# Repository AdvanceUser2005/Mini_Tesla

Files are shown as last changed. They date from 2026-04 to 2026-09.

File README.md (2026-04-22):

# Mini Tesla — Autonomous Mecanum Robot Platform

## Members
Daksh Gupta, Computer Engineering Student (2028)
mailtodaksh@vt.edu

## Mentor
MENTOR NAME HERE

## Current Status
IN PROGRESS

## Project Overview

The Mini Tesla is an autonomous omnidirectional robotic platform built on a four-wheel mecanum drivetrain, capable of moving in any direction — forward, lateral, diagonal, and rotational — without needing to reorient itself. The platform is designed as a full-stack research and engineering vehicle that bridges mechanical design, embedded systems, and autonomous robotics software.

At the mechanical core, the robot features a custom-built two-ratio gearbox designed and fabricated in-house, enabling adaptive gear shifting between high-speed flat terrain mode and high-torque incline traversal mode. The drivetrain uses four Pololu 37D bare DC motors (24V, 64 CPR encoder, no internal gearbox) feeding directly into the custom transmission — maximizing regenerative braking efficiency by eliminating the energy loss of a factory gearbox. Custom spring-damper shock absorbers are designed and tuned for outdoor terrain traversal, and a hydraulic braking circuit — engineered from first principles including master/slave cylinder sizing and fluid bleeding — provides active braking and hill-hold capability.

The autonomy stack runs on an NVIDIA Jetson Orin Nano Super (67 TOPS) executing ROS 2, with a Teensy 4.1 microcontroller handling real-time motor control, PID velocity loops, encoder feedback, and actuator commands over CAN/serial. Perception is handled by an Intel RealSense D435 RGB-D camera and an RPLIDAR A1 2D LiDAR, enabling SLAM-based mapping, Nav2 autonomous navigation, and an Automatic Emergency Braking (AEB) system via depth threshold detection. An AI pipeline running YOLO on the Jetson GPU enables object detection and person-following behavior. The robot also supports WiFi and Bluetooth remote control for manual override alongside full autonomous operation.

A digital twin of the platform is built in NVIDIA Isaac Sim, enabling hardware-in-the-loop (HIL) simulation and algorithm validation before deployment to the physical robot. The project spans three semesters — Spring, Summer, and Fall 2026 — with three defined milestones culminating in a full autonomous demonstration.

## Educational Value Added

This project develops hands-on expertise across six engineering disciplines simultaneously, making it one of the most comprehensive student robotics projects in scope:

**Mechanical Design & Manufacturing** — Students learn to design a multi-ratio planetary gearbox from scratch, understanding gear ratio theory, torque multiplication, and how automotive transmissions work at a fundamental level. Custom shock absorbers are designed using spring-damper physics, spring rate selection (k = F/x), and damping coefficient tuning. A hydraulic brake circuit is engineered from Pascal's Law up — including master/slave cylinder bore sizing, brake fluid selection, and system bleeding technique. FEA (Finite Element Analysis) is used to validate structural components before fabrication.

**Embedded Systems & Real-Time Control** — The Teensy 4.1 runs deterministic real-time firmware handling four simultaneous quadrature encoder interrupts, four independent PID velocity loops, PWM motor command output, servo control for the gear selector, and solenoid actuation for the hydraulic brake — all at 1 kHz without timing conflicts. Students learn CAN bus communication, hardware timer configuration, and interrupt-driven architecture.

**Robotics Software (ROS 2)** — The full ROS 2 stack is implemented from scratch: mecanum inverse kinematics node, wheel odometry, IMU-fused localization, SLAM mapping with RPLIDAR, and Nav2 goal-directed navigation with dynamic obstacle avoidance. Students learn node architecture, topic/service communication, and real-time sensor fusion.

**AI & Computer Vision** — YOLO object detection and person re-identification pipelines run on the Jetson GPU for human-following behavior. The AEB system uses raw RealSense depth data — not AI — for sub-25ms obstacle detection latency, teaching students the difference between classification tasks and safety-critical sensor pipelines.

**Simulation & Digital Twin** — NVIDIA Isaac Sim is used to build a full digital twin of the robot including geometry, sensors, and drivetrain physics. Students learn hardware-in-the-loop testing workflows and sim-to-real transfer techniques used in industry robotics development.

**Communications & Controls** — WiFi and Bluetooth modules provide remote control capability alongside the autonomous stack. Students implement mode-switching logic, teleop integration in ROS 2, emergency stop handling, and failsafe behavior.

## Tasks

### Spring 2026 (Now → May 13)
- [ ] Finalize BOM and place all component orders (motors, MCU, sensors, battery, structural hardware)
- [ ] CAD — Full chassis design in SolidWorks/Fusion 360
- [ ] CAD — Custom 2-ratio gearbox (planetary stages, selector collar, housing)
- [ ] CAD — Shock absorber assemblies (spring-damper bodies, mount points)
- [ ] CAD — Hydraulic brake system (caliper, rotor, master cylinder, lines)
- [ ] FEA — Structural analysis on chassis and gearbox housing
- [ ] Receive and inventory all ordered components
- [ ] Begin manufacturing drawings for CNC/3D print parts

### Summer 2026 (May 26 → July 6)
- [ ] 3D print and CNC machine all custom parts (gearbox bodies, shock housings, brake calipers)
- [ ] Full mechanical assembly — chassis, wheels, gearboxes, shock absorbers
- [ ] Wire all electronics — Teensy, motor drivers, IMU, LiDAR, RealSense, AI PC, WiFi/BT module
- [ ] Flash Teensy firmware — encoder interrupts, PID loops, CAN comms
- [ ] Validate mecanum kinematics — test all four motion vectors
- [ ] Test power regeneration — verify BTS7960 back-EMF current return
- [ ] Test gearbox shifting — servo-actuated selector under load
- [ ] Test hydraulic brakes — caliper engagement, hill-hold force
- [ ] Test remote control — WiFi/BT manual override
- [ ] Isaac Sim — build digital twin, run full-scale simulation tests
- [ ] **MILESTONE #2 target: June 13** — Assembly complete, all wiring done, basic subsystem testing done

### Fall 2026 (Aug 24 → Dec 16)
- [ ] Camera integration — RealSense depth layer into Nav2 costmap
- [ ] AEB system — depth threshold node with real-time priority, direct Teensy serial path
- [ ] YOLO object detection pipeline on Jetson GPU
- [ ] Person-following behavior node
- [ ] Full Nav2 autonomous navigation on real hardware
- [ ] SLAM map generation and localization validation
- [ ] Full system integration testing — all subsystems running simultaneously
- [ ] Documentation — architecture writeup, wiring diagrams, software README
- [ ] **MILESTONE #3 target: Dec 16** — Full autonomous run demonstration

## Design Decisions

**Motor Selection — Pololu 37D Bare Motor (24V, no internal gearbox)**
Chosen over motors with factory gearboxes specifically because the custom gearbox IS the project. Using a bare motor means the only reduction stage is our custom 2-ratio transmission, which maximizes back-drive efficiency for regenerative braking (no factory gearbox eating energy in reverse) and gives us full control over gear ratios. The 64 CPR encoder provides tight velocity feedback for PID.

**Motor Driver — Cytron MDD10A × 2**
Chosen over BTS7960 because it is purpose-built for the 10-12A peak current range of our motors, includes proper overcurrent/overheat protection, has cleaner PWM response, and covers two motors per board — reducing wiring complexity from four boards to two. Supports regenerative braking current routing.

**Microcontroller — Teensy 4.1**
600 MHz ARM Cortex-M7 provides sufficient headroom to run four encoder interrupts, four PID loops, CAN comms to Jetson, servo PWM for gear selector, and hydraulic brake solenoid control simultaneously without timing conflicts. Native CAN bus and solid micro-ROS support for ROS 2 integration via serial.

**Perception — RealSense D435 + RPLIDAR A1 (no OAK-D)**
LiDAR handles 2D SLAM with superior reliability on blank walls and in low light. RealSense adds 3D depth for AEB and close-range obstacle detection. The OAK-D was evaluated and dropped — once LiDAR is in the stack, OAK-D has no unique role. The combo of RealSense + LiDAR outperforms OAK-D + LiDAR in both indoor reliability and outdoor sunlight conditions.

**AEB Design — Depth Threshold, Not Image Recognition**
AEB latency requirement is sub-25ms. Neural network inference adds 50-120ms before a brake signal is even sent. The AEB node reads raw RealSense depth frames, checks the minimum depth value in a forward-facing region of interest, and fires directly to the Teensy over a dedicated high-priority serial path — bypassing the ROS nav stack entirely. Total pipeline latency: ~15-20ms.

**Gearbox — Per-Wheel (not shared axle)**
Each mecanum wheel must spin at an independently controlled speed. Any mechanical coupling between two wheels (e.g. shared differential) destroys omnidirectional capability. All four gearboxes shift simultaneously via a single servo command from Teensy, maintaining synchronized gear state across all wheels.

**No AK60-6 Actuators**
CubeMars AK60-6 was evaluated — excellent motors with integrated FOC and CAN — but at ~$220/unit ($880 for 4 wheels) they consume over half the total budget before any other component is purchased. The Pololu 37D + custom gearbox achieves the educational objectives of the project at a fraction of the cost.

## Design Misc

- **Gearbox Ratios**: High gear 1:1 (flat terrain, max speed), Low gear 2:1 (inclines, max torque). With Pololu 37D at 24V, low gear provides approximately 2× the climbing force.
- **Shock Absorber Tuning**: Spring rate selected based on estimated robot mass ~10-12 kg. Rebound damping oil viscosity to be tuned empirically during summer assembly phase.
- **Hydraulic Brake Hold Force**: Sized to hold robot stationary on 20° incline at full load. Master cylinder bore sized for solenoid actuation force available from Teensy-controlled valve.
- **Regenerative Braking Efficiency**: With bare motor (no internal gearbox) and 1:1 or 2:1 custom transmission, estimated 45-55% energy recovery vs ~12% with a factory 50:1 gearbox.
- **Stereo LiDAR**: If additional 3D mapping capability is needed beyond RealSense, stereo depth from RealSense is fed into RTAB-Map as a second mapping layer. No OAK-D needed.
- **WiFi/BT Remote Control**: Implemented as a ROS 2 teleop node. Autonomous mode and teleop mode are mutually exclusive with a hardware-level mode switch. Emergency stop works in both modes.

## Steps for Documenting Your Design Process

1. **CAD Files** — All SolidWorks/Fusion 360 files version-controlled in project GitHub repo under `/cad`. Export STLs and STEP files for each manufactured part alongside manufacturing drawings (PDF).
2. **FEA Reports** — Document load cases, boundary conditions, mesh parameters, and safety factors for each analyzed component. Export simulation screenshots and summary tables to `/docs/fea`.
3. **Wiring Diagrams** — Full schematic in KiCad or Fritzing showing every electrical connection: Teensy pinout, motor driver wiring, sensor connections, power distribution. Stored in `/docs/electrical`.
4. **Firmware** — Teensy firmware in `/firmware` with inline comments explaining each PID parameter, CAN message format, and interrupt configuration. Include a README with flash instructions.
5. **ROS 2 Packages** — Each subsystem (kinematics, navigation, perception, AEB) is its own ROS 2 package in `/ros2_ws/src`. Include launch files and parameter YAML files.
6. **Test Logs** — After each milestone, document test results: motor RPM vs command, PID step response plots, LiDAR scan accuracy, navigation success rate. Stored in `/docs/test_logs`.
7. **Weekly Log** — Update the Log section of this document every week with what was completed, what blocked progress, and what is planned next.

## BOM + Component Cost

| Component | Category | Qty | Unit Cost | Total |
|---|---|---|---|---|
| NVIDIA Jetson Orin Nano Super (8GB) | Compute | 1 | $249 | $249 |
| Teensy 4.1 Microcontroller | Embedded Control | 1 | $30 | $30 |
| Pololu 37D Bare DC Motor (24V, 64 CPR Encoder) | Drivetrain | 4 | $37.50 | $150 |
| Custom CNC Gearbox — Aluminum, 2-ratio (materials est.) | Transmission | 4 | ~$40 | ~$160 |
| Servo Motor (Gear Selector Actuator) | Transmission | 1 | $30 | $30 |
| Cytron MDD10A Dual Motor Driver | Power Electronics | 2 | $30 | $60 |
| Intel RealSense D435 RGB-D Camera | Perception | 1 | $399 | $399 |
| RPLIDAR A1 (2D LiDAR) | Perception | 1 | $100 | $100 |
| IMU — BNO055 | Sensing | 1 | $25 | $25 |
| WiFi / Bluetooth Module | Communications | 1 | $25 | $25 |
| LiPo Battery Pack (22.2V, 10Ah) | Power | 1 | $150 | $150 |
| Power Management / BMS Board | Power | 1 | $80 | $80 |
| Robot Chassis (Aluminum Frame, Final Stage) | Structure | 1 | $180 | $180 |
| Wiring, Connectors, Fasteners, Misc. Hardware | Misc. | — | — | $120 |
| **TOTAL** | | | | **~$1,758** |

> Custom gearbox cost is a materials estimate only. Machining is done in-house using university shop access. ROS 2, NVIDIA Isaac Sim, and all software tools are free / open-source.

## Timeline

### Spring 2026 — Now → May 13
**Goal**: All CAD complete, all parts ordered and received, FEA validated

| Week | Focus |
|---|---|
| Now – Week 2 | Finalize BOM, place all component orders |
| Week 2 – 4 | CAD — Chassis, gearbox, shock absorbers, hydraulic brakes |
| Week 4 – 5 | FEA analysis on chassis and gearbox housing |
| Week 5 – 6 | Manufacturing drawings, send files to shop / begin 3D printing |
| **May 13** | **🏁 MILESTONE #1 — Chassis (physical), Wheels (mounted), Gearbox (CAD), Brakes (CAD), Shockers (CAD)** |

---

### Summer 2026 — May 26 → July 6
**Goal**: Fully assembled and wired robot with all subsystems individually tested

| Week | Focus |
|---|---|
| Week 1 | 3D print and CNC all custom parts |
| Week 2 | Full mechanical assembly — chassis, gearboxes, shock absorbers, wheels |
| Week 3 | All electronics wiring — Teensy, motor drivers, LiDAR, RealSense, IMU, WiFi/BT, AI PC |
| Week 4 | Teensy firmware — encoders, PID, CAN/serial, gear selector, brake solenoid |
| Week 5 | Testing — mecanum kinematics, regen braking, gearbox shifting, hydraulic brakes |
| Week 6 | Remote control integration + Isaac Sim full-scale simulation |
| **June 13** | **🏁 MILESTONE #2 — Full assembly complete, all wiring done, gearbox + brakes + remote tested** |

> *Break period: July 6 – August 24*

---

### Fall 2026 — Aug 24 → Dec 16
**Goal**: Full autonomous robot with AI perception, SLAM navigation, and AEB — demonstrated live

| Week | Focus |
|---|---|
| Week 1 – 2 | Camera integration — RealSense depth into Nav2 costmap + SLAM |
| Week 3 – 4 | AEB system — depth threshold node, dedicated serial path to Teensy |
| Week 5 – 6 | AI pipeline — YOLO object detection + person following on Jetson |
| Week 7 – 8 | Full ROS 2 stack on hardware — Nav2, localization, sensor fusion |
| Week 9 – 10 | System integration — all subsystems running simultaneously |
| Week 11 – 12 | Testing, debugging, performance tuning |
| Week 13 – 14 | Documentation — architecture writeup, wiring diagrams, software README |
| **Dec 16** | **🏁 MILESTONE #3 — Full autonomous demo: SLAM map, navigate to goal, detect person, AEB trigger** |

## Useful Links

- [Pololu 37D Metal Gearmotor (Bare, 24V, Encoder)](https://www.pololu.com/category/116/37d-mm-metal-gearmotors)
- [Cytron MDD10A Dual Motor Driver](https://www.cytron.io/p-10amp-5v-30v-dc-motor-driver-2-channels)
- [Teensy 4.1 — PJRC](https://www.pjrc.com/store/teensy41.html)
- [NVIDIA Jetson Orin Nano Super Developer Kit](https://developer.nvidia.com/embedded/jetson-orin-nano-developer-kit)
- [Intel RealSense D435](https://www.intelrealsense.com/depth-camera-d435/)
- [RPLIDAR A1](https://www.slamtec.com/en/Lidar/A1)
- [ROS 2 Humble Documentation](https://docs.ros.org/en/humble/)
- [Nav2 Documentation](https://docs.nav2.org/)
- [NVIDIA Isaac Sim](https://developer.nvidia.com/isaac-sim)
- [micro-ROS for Teensy](https://micro.ros.org/)
- [SimpleFOC Library](https://simplefoc.com/)
- [RTAB-Map ROS 2](https://github.com/introlab/rtabmap_ros)

## Log

### Week of April 21, 2026
- Project proposal drafted and submitted
- Component decisions finalized: Pololu 37D bare motor, Cytron MDD10A, Teensy 4.1, RealSense D435 + RPLIDAR A1
- Decided against OAK-D Lite (redundant with RealSense + LiDAR combo)
- Decided against AK60-6 actuators (over budget at $880 for 4 wheels)
- AEB architecture decided: depth threshold on raw RealSense frames, dedicated high-priority serial path to Teensy — no image recognition in the braking loop
- Three-semester timeline established with three milestones (May 13, June 13, Dec 16)
- PowerPoint proposal finalized and submitted
- **Next steps**: Begin chassis CAD, finalize BOM pricing, place first component orders

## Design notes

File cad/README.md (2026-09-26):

# CAD

All mechanical CAD for Mini Tesla. Right now that means the **10C4I** indoor mecanum prototype. 15C4I (the outdoor gear-changing car) has no CAD in this repo yet.

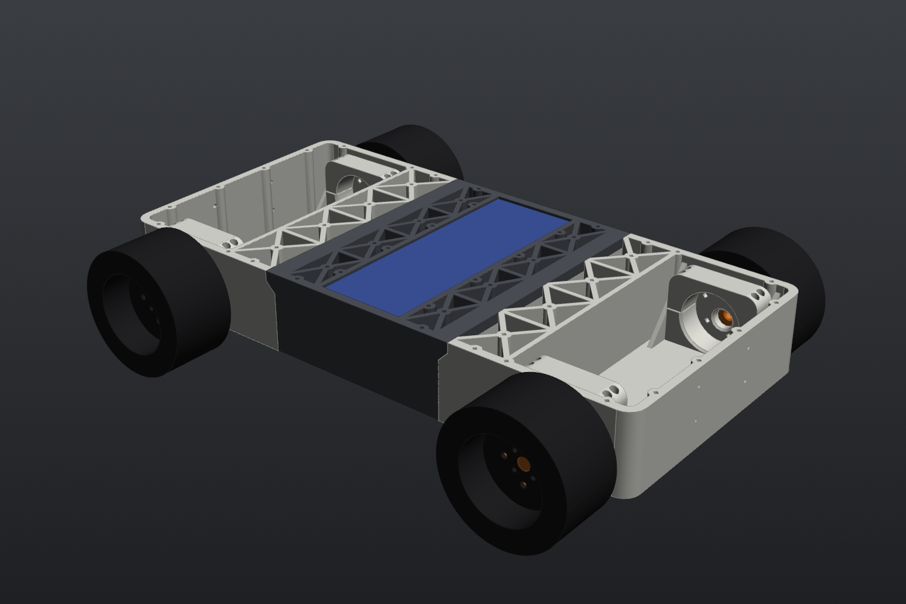
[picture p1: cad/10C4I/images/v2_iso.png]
10C4I v2 assembled


## What's here

| Item | Status | Doc | Files |
|---|---|---|---|
| 10C4I chassis v2 (overview, assembly, hardware) | Designed, **not printed yet**: waiting on coupon results | [10C4I/README.md](10C4I/README.md) | `10C4I/step/10C4I_v2_assembly.step` |
| Center section ×1 | Designed | [parts/center_section.md](10C4I/parts/center_section.md) | `10C4I_v2_center_section_x1.{step,stl}` |
| End section ×2 (front = rear) | Designed | [parts/end_section.md](10C4I/parts/end_section.md) | `10C4I_v2_end_section_x2.{step,stl}` |
| Motor cap ×4 | Designed | [parts/motor_cap.md](10C4I/parts/motor_cap.md) | `10C4I_v2_motor_cap_x4.{step,stl}` |
| Wheel adapter ×4 | Designed | [parts/wheel_adapter.md](10C4I/parts/wheel_adapter.md) | `10C4I_v2_wheel_adapter_x4.{step,stl}` |
| Tolerance coupon | Ready to print, **print this first** | [parts/tolerance_coupon.md](10C4I/parts/tolerance_coupon.md) | `10C4I_tolerance_coupon.{step,stl}` |
| Top mount-point map (56 M2.5 inserts) | Done | [mount_points/](10C4I/mount_points/) | `.csv` + `.png` |
| Bare-motor 2-stage gearbox ×2 | **Not modeled yet**: needs pinion measurements | [parts/bare_motor_gearbox.md](10C4I/parts/bare_motor_gearbox.md) | none |
| Chassis v1 | Superseded by v2, files not kept | [parts/v1_chassis.md](10C4I/parts/v1_chassis.md) | none |

## Layout

```
cad/10C4I/
├── README.md        overall chassis: dimensions, hardware, print + assembly
├── src/             CadQuery source (the real source of truth)
├── step/            STEP per part + assembly (open these in Fusion)
├── stl/             print-ready STLs, already in print orientation
├── mount_points/    coordinates of every mounting insert
├── images/          renders used in these docs
└── parts/           one page per part
```

## How the CAD is made

The 10C4I parts are **code, not Fusion files**. They're written in [CadQuery](https://cadquery.readthedocs.io/) (Python). Every dimension lives as a variable at the top of `src/mini_tesla_10c4i_v2.py`, so a fit change is one number and a re-run:

```bash
pip install cadquery shapely
cd cad/10C4I/src
OUT_DIR=out python mini_tesla_10c4i_v2.py      # -> STEP + STL per part + assembly
OUT_DIR=out python tolerance_coupon.py
```

The script also pulls in Pololu's motor model as a reference body. To include it, put `37d-gearmotor-19-30-encoder.step` from Pololu's #4691 page next to the script, or point `MOTOR_STEP` at it. The committed assembly STEP is exported **without** the motor and wheel reference bodies (~5 MB instead of ~27 MB). It has every printed part plus `REF_battery_6S_5200`, so the `REF_motor_*` and `REF_wheel_*` bodies you see in Fusion aren't in it.

> **Edits made in Fusion don't flow back into the script.** Change fits and dimensions in the script. Use Fusion for *new* brackets designed against the STEP.

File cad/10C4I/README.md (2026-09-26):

# 10C4I chassis v2

A 3D-printed, 3-section mecanum chassis built around the real parts: Pololu 37D 19:1 gearmotors, REV DUO 75 mm mecanum wheels, and a Turnigy 6S 5200 mAh pack. It carries a Jetson Orin Nano Super and the Velodyne Puck LITE on top.

| Assembled | Exploded |
|---|---|
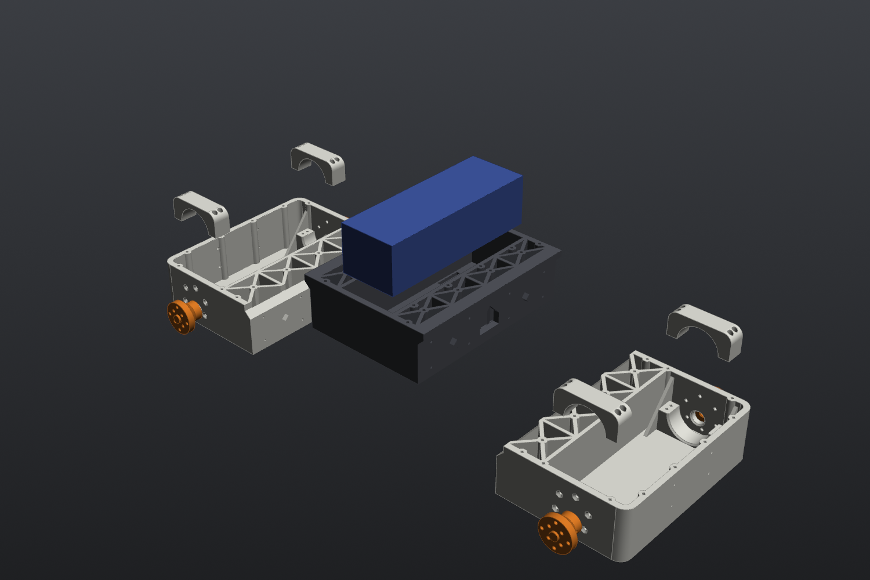
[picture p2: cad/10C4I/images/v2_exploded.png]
|  |  |

## Key dimensions

| | mm |
|---|---|
| Body length × width × height | 356 × 170 × 49 |
| Width over wheels | ~258 |
| Wheelbase / track (wheel centres) | 266 / 217 |
| Ground clearance (floor underside) | 21 |
| Top face above ground | 70 |
| Section length (all three identical) | 118.7 (+6 mm lap lip on each end of the center) |

The footprint is sized to roughly a 16" MacBook Pro. 170 mm is the narrowest body the battery fits across.

**Coordinates** (script, STEP and the mount-point CSV): X forward, Y left, Z up. Z = 0 is the chassis underside, origin at the robot's centre.

## Parts

| Part | Qty | Print size (mm) | Solid volume | Page |
|---|---|---|---|---|
| Center section | 1 | 130.7 × 170 × 49 | 393 cm³ | [center_section.md](parts/center_section.md) |
| End section (front = rear) | 2 | 118.7 × 170 × 49 | 299 cm³ | [end_section.md](parts/end_section.md) |
| Motor cap | 4 | 56 × 16 × 22.8 | 10.6 cm³ | [motor_cap.md](parts/motor_cap.md) |
| Wheel adapter | 4 | Ø31 × 21.7 | 8.8 cm³ | [wheel_adapter.md](parts/wheel_adapter.md) |
| Tolerance coupon | 1 | 104 × 70.5 × 34 | 60 cm³ | [tolerance_coupon.md](parts/tolerance_coupon.md) |

Every part fits the Prusa MK4S bed (250 × 210 × 220) and prints **without supports, in the orientation it's exported in**.

## Design rules

- **Fasteners:** M3 is used *only* at the motor faces, because that's what Pololu tapped. Everything printed-to-printed is **M2.5 into heat-set inserts**.
- **Inserts:** Pofsnnx M2.5 × 4 mm long × 3.5 mm OD. Pilot hole is 3.1 mm (pending coupon). Use the 4 mm-long ones everywhere; all screw lengths assume them.
- **Tolerances:** every clearance is in one block at the top of `src/mini_tesla_10c4i_v2.py`:

| Variable | Value | What |
|---|---|---|
| `INS_M25` | 3.1 | M2.5 insert pilot hole |
| `INS_DEPTH` | 6.0 | blind depth for inserts |
| `CLR_M25_V` / `CLR_M25_H` | 2.9 / 3.0 | M2.5 clearance, hole vertical / horizontal in print |
| `CLR_M3_H` | 3.4 | M3 clearance through the motor walls |
| `CSK_M3_D` | 6.4 | 90° countersink for M3 flat heads |
| `BUSH_D` | 12.3 | gearbox bushing (12.0 nominal) |
| `SLIDE` | 0.25 | per-side clearance on pegs and the lap joint |
| `GB_BORE` | 37.2 | clamp bore over the Ø36.8 gearbox |
| `CLAMP_GAP` | 0.8 | cap sits this high so screws actually clamp |
| `DBORE_D` / `DFLAT` | 6.15 / 2.45 | wheel adapter D-bore |

## Hardware

| Qty | Part | Where |
|---|---|---|
| 24 | M3×8 countersunk (flat head) | motor faces, 6 per motor. Leaves 2.5 mm of thread in the gearbox (Pololu max 3 mm) |
| 16 | M2.5×10 socket head | section joints, 8 per joint |
| 16 | M2.5×16 socket head | motor caps, 4 per cap |
| 32 | M2.5×6 socket head | wheels, 8 per wheel ¹ |
| 4 | M2.5×6 cup-point set screw | wheel adapter onto the shaft flat |
| 68 | M2.5 heat-set inserts (assembly) | 16 joint + 16 clamp + 32 wheel + 4 set-screw |
| up to 56 | M2.5 heat-set inserts (mounting) | 48 top face + 2×2 per bumper, install as needed |
| 2 | 20 mm velcro straps | battery |

¹ The chat's list said 16 (4 per wheel). That was before the adapter went to 8 inserts, so 32 is the updated count. Check the length against the wheel web (2.4 mm) once you have one in hand.

## Printing

- Filament per the BOM: **PA612-CF**. Use a hardened nozzle, dry the spool, and put glue stick on the bed (170 mm wide nylon flats like to curl).
- Roughly 1.1–1.2 kg for the whole chassis.
- **Print the coupon first.** Don't print the big sections until the coupon numbers are in the script.

## Assembly order

1. Heat-set all assembly inserts: joint inserts in the center bulkheads, clamp inserts in the end-section saddles, and 9 per wheel adapter.
2. **Motors (left first on each end):** drop the motor in about 22 mm inboard, then slide it outboard until the gearbox bushing seats in the wall hole. Lift it ~1.5 mm as the gearbox enters the clamp. Fit 6× M3×8 flat heads from outside; they sit flush because the wheel is only 3 mm off the wall. The encoder cable tab is clocked to clear the floor.
3. Motor cap on top of each gearbox with 4× M2.5×16.
4. Wheel adapter onto the D-shaft, set screw on the flat, then the wheel with 8× M2.5×6.
5. Battery into the center bay, two straps through the floor slots.
6. **Join sections:** lower the center section so its lap lips rest on the end bulkheads, with the diamond pegs in their sockets. Then drive 8× M2.5×10 per joint from the end-section side. Motor cables pass through the cable windows.

Install paths and interferences were checked in the model: no part overlaps, the motor face holes match Pololu's STEP within 0.02 mm, and neither motor hits anything on the way in, including the second motor sliding in next to the first.

## Open items

- [ ] Print the coupon and plug the results into the tolerance block (see [tolerance_coupon.md](parts/tolerance_coupon.md))
- [ ] Two corners run bare #4690 motors and need the printed 2-stage gearbox. The current end section only fits the geared #4691. See [bare_motor_gearbox.md](parts/bare_motor_gearbox.md)
- [ ] Print one wheel adapter and test it in a wheel before printing four. The inside of the REV hub cup couldn't be measured
- [ ] Jetson plate, LiDAR mount and D435 bracket: not designed yet. They go on the [mount points](mount_points/)

## Source parts

Real-part data the design is built from:

| Part | Used for |
|---|---|
| Pololu #4691, 37D 19:1 gearmotor + 64 CPR encoder (Pololu STEP) | Gearbox Ø36.8, can Ø34.8, encoder Ø34.0, 6× M3 on a 31 mm circle, 3 mm thread depth, shaft 6 mm D, offset from gearbox centre |
| REV DUO 75 mm mecanum (REV-41-1656/1657, drawing) | Web holes 4× Ø4.0 on 24 mm circle, 4× Ø3.0 on 16 mm circle, Ø8.1 bore, 40.8 wide, web 19.2 inside the wheel |
| Turnigy 6S 5200 mAh | 156 × 54 × 45 envelope, designed for 1 kg |
| Pofsnnx M2.5 inserts | 3.5 mm OD, 4 mm long |

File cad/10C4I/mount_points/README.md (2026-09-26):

# Mount points

These are the M2.5 heat-set insert positions for anything bolted onto the chassis later: the Jetson plate, the LiDAR mount, the D435 bracket, the Teensy and drivers. Design those brackets in Fusion against `step/10C4I_v2_assembly.step` and snap them to these holes.

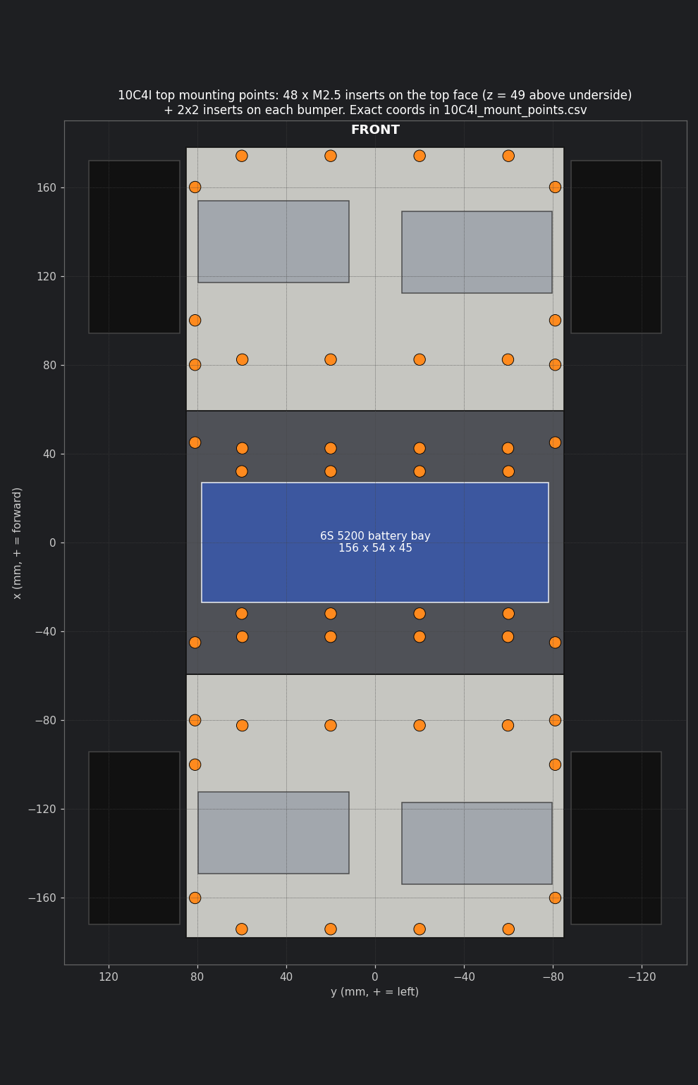
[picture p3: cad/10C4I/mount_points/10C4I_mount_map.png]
mount map


- **48 on the top face,** all at z = 49 mm above the chassis underside (70 mm above ground): 20 on the center section and 14 on each end section. The ones around the battery bay are placed so a plate can bridge over the pack.
- **8 on the bumpers:** a 2×2 pattern on each bumper face, at y = ±25 and z = 18 and 38.

`10C4I_mount_points.csv` lists every point with its section, x (forward from robot centre), y (left), z (from the underside) and type. The coordinates match the STEP assembly frame.

Install inserts only where you actually bolt something.

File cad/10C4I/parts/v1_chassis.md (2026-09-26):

# Chassis v1 (superseded)

**Status:** replaced by v2. Its files are **not** in the repo. This page records what it was and why it changed.

v1 was a first pass built entirely on **assumed** dimensions, before the real part files and datasheets were available. It kept the same idea: 3 printed sections, with front and rear as the same part.

| | v1 | v2 |
|---|---|---|
| Parts | center ×1, end ×2, motor cap ×4, splice plate ×2 | center ×1, end ×2, motor cap ×4, wheel adapter ×4 |
| Body | 420 × 190 × 30 (200 center + 2 × 110 ends) | 356 × 170 × 49 (3 × 118.7) |
| Wheels | assumed 100 mm, 45 wide | real REV DUO 75 mm |
| Motor clamp | around the Ø37 "can" (assumed) | around the Ø36.8 gearbox, from Pololu's STEP |
| Joints | stepped lap, tongue/groove, 8× M5 flange bolts, bottom splice plate | 45° lap lip, diamond pegs, 8× M2.5 into inserts |
| Fasteners | M5 / M4 / M3 inserts | M3 at motor faces only, M2.5 + inserts everywhere else |
| Battery | no bay; flat deck with a 44-hole M3 insert grid | in a bay inside the center section |
| Cross grid | on the underside | on the top face, to match the reference photo |

## Why it changed

- The real Pololu STEP showed the can is Ø34.8, not 37, so the v1 clamp would have been loose. The M3 face threads are also only 3 mm deep.
- The real wheels are 75 mm with a specific hub pattern, which changed the axle height, track and adapter.
- The design constraints were set: fit the MK4S bed in equal sections, cross grid like the reference, M2.5 everywhere except the motor faces, and a MacBook-sized footprint.
- The battery moved inside for a lower CG and a free top deck.

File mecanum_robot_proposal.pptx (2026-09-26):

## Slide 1

Creating our own in house
Mini Tesla

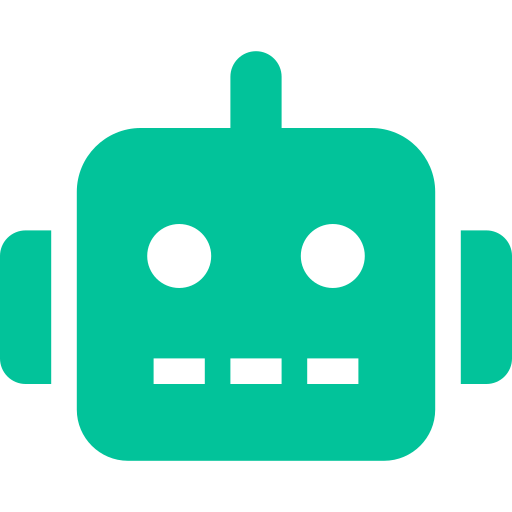
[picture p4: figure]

Mecannum Drive Train

Full Autonomous Stack

Energy Generation

Sensor Fusion

Mini Tesla| Project Proposal

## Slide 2

PROJECT OVERVIEW

System Architecture

Project Goal

An autonomous omnidirectional robot platform built on four mecanum wheels, capable of moving in any direction without rotating. It features an adaptive gear transmission that shifts between speed and torque modes to handle inclines, paired with custom-built shock absorbers and hydraulic brakes for real-world terrain. The brain is an NVIDIA Jetson Orin running a full ROS 2 autonomy stack with AI-based object detection, person following, and SLAM navigation. A digital twin in NVIDIA Isaac Sim mirrors the real robot for safe hardware-in-the-loop testing before any code hits the physical platform.

Integrate regenerative energy recovery for extended battery life.

LiDAR
2D Scan

NVIDIA Jetson
Orin
ROS 2 | AI | Nav

Isaac
Sim
Digital Twin

RealSense
RGB-D Camera

HIL

IMU
Orientation

Teensy 4.1
Real-Time Control

4× Mecanum Wheels + Motor Drivers + Gear Box + Hydraulic Breaks

Deploy AI-based perception: object detection & human following.

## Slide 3

KEY CAPABILITIES

Omnidirectional
Mobility

4-wheel mecanum drive for forward, lateral, diagonal & rotational motion

AI Perception

SLAM mapping, global path planning and local obstacle avoidance with object detection + person following via reinforcement learning on Jetson

Adaptive Drivetrain

Multi-ratio gear shifting for flat terrain speed vs incline torque

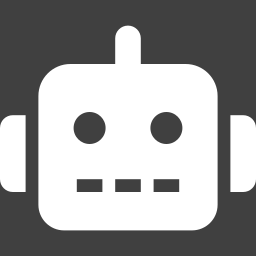
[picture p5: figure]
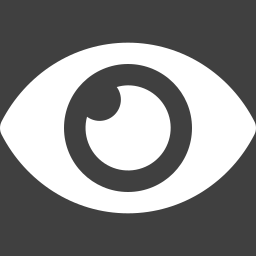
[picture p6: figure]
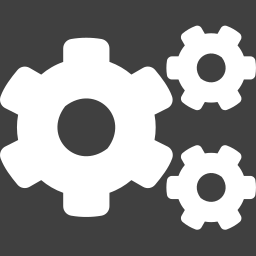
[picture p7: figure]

Energy Regeneration

Free-wheel mode with regenerative braking to recharge onboard battery

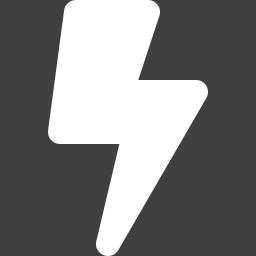
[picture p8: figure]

AEB - Autonomous Emergency Braking

SLAM mapping, global path planning and local obstacle avoidance

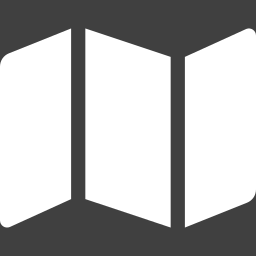
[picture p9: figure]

Digital Twin (Isaac Sim)

Full simulation environment for hardware-in-the-loop testing

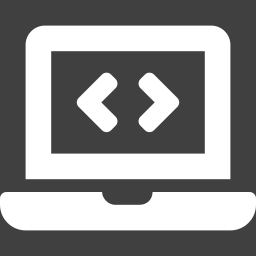
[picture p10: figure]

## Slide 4

EDUCATIONAL VALUE

Working on this project develops expertise across five high-demand engineering disciplines:

Embedded Systems

- Real-time control with Teensy 4.1
- PWM motor driving & encoder feedback
- PID control loop implementation
- CAN / serial communication protocols

Mechanical Design

- Mecanum drivetrain kinematics
- Planetary gearbox integration
- Servo-actuated gear selector
- Regenerative energy circuit design

Robotics Software (ROS 2)

- Node-based modular architecture
- SLAM mapping & localization
- Nav2 autonomous navigation
- Sensor fusion & odometry

AI & Computer Vision

- Neural network object detection
- Person re-identification & tracking
- Depth-camera obstacle perception
- Edge inference on Jetson GPU

Simulation & Testing

- NVIDIA Isaac Sim 3D environment
- Hardware-in-the-loop testing (HIL)
- Digital twin validation workflow
- Sim-to-real transfer techniques
- FEA – Finite Element Analysis

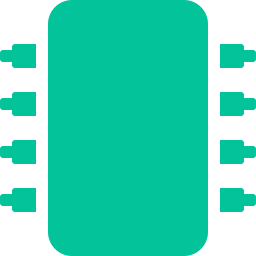
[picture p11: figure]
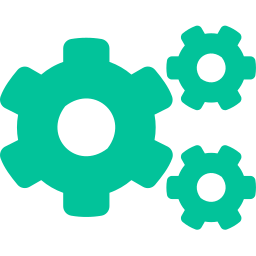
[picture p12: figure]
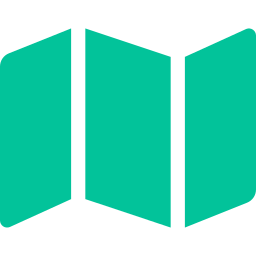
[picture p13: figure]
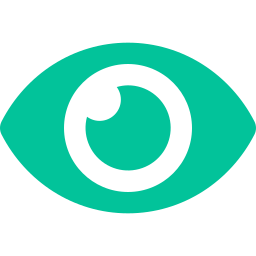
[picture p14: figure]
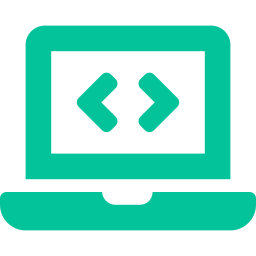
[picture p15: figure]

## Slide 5

COMPONENT COST ESTIMATE

Component

Category

Qty

Unit Cost

Total

NVIDIA Jetson Orin Nano (8GB)

Teensy 4.1 Microcontroller

Compute

Embedded Control

1

1

$249

$30

$249

$30

DC Bare Motors

Drivetrain

4

$37.5

$150

Planetary Gearbox ( Aluminum CNC – Last Stage)

Servo Motor (Gear Selector)

Transmission

Transmission

4

1

NA

$30

NA

$30

Motor Drivers (Cyton MDD10A)

Intel RealSense D435 Camera

Power Electronics

Perception

2

1

$30

$399

$60

$399

RPLIDAR A1 (2D LiDAR)

IMU (BNO055)

Perception

Sensing

1

1

$100

$25

$100

$25

Wheel Encoders

Sensing

4

$12

$48

LiPo Battery Pack (22.2V 10Ah)

Power Management / BMS Board

Power

Power

1

1

$150

$80

$150

$80

Robot Chassis (Aluminum Frame Final Stage)

Wiring, Connectors, Misc. Hardware

Structure

Misc.

1

—

$180

—

$180

$120

$1,621

TOTAL ESTIMATED COST

* Prices are approximate. Shipping not included. Software tools (ROS 2, Isaac Sim) are free / open-source.

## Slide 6

PROJECT TIMELINE (16 Weeks)

Phase

Planning & Procurement

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
Key Deliverables

Literature review · BOM · Component ordering

01

02

Mechanical Assembly

W3–W5

Chassis · Gearbox · Mecanum wheel mount

03

Embedded Hardware

Motor drivers · Encoders · Teensy firmware

04

Motor Control & Comms

PID tuning · CAN bridge · Kinematics

Autonomy Stack (ROS 2)

SLAM · Nav2 navigation · Sensor fusion

05

06

AI Perception

Object detection · Person following

07

Digital Twin (Isaac Sim)

★ Demo

Isaac Sim setup · HIL · Sim-to-real

08

Integration & Demo

System test · Docs · Final demo

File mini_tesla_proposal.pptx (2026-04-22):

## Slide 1

Creating Our Own
In-House

Mini Tesla

Autonomous Mecanum Drive Robot Platform


Mecanum Drive Train

Sensor Fusion

Full Autonomous Stack

Remote Control

Energy Generation

ECE Project Proposal | Virginia Tech

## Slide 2

PROJECT OVERVIEW

Project Goal

Build an omnidirectional mecanum-drive robot — our own in-house Mini Tesla.

System Architecture

LiDAR
2D Scan

NVIDIA Jetson
Orin Nano
ROS 2 | AI | Nav

HIL

Custom-built gearbox with adaptive gear shifting for incline traversal.

RealSense
RGB-D Camera

Isaac
Sim
Digital Twin

Design shock absorbers & hydraulic brakes from scratch for real terrain.

IMU
Orientation

WiFi/BT
Remote Control

Deploy AI: object detection, human following & AEB emergency braking.

Teensy 4.1
Real-Time Control

WiFi/Bluetooth remote control with full ROS 2 autonomous stack.

Validate via NVIDIA Isaac Sim digital twin before hardware deployment.

4× Mecanum + Gearbox + Hydraulic Brakes

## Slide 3

KEY CAPABILITIES

Omnidirectional Drive

4-wheel mecanum drive — forward, lateral, diagonal, rotation, all without turning.

AI Perception

Object detection, human following & AEB emergency braking via RealSense + Jetson.

Custom Gearbox

In-house built 2-ratio transmission with servo-actuated selector for incline torque.

Energy Regeneration

Free-wheel motor-as-generator mode redirects kinetic energy back to LiPo battery.


Autonomous Navigation

SLAM + Nav2 path planning with LiDAR localization and dynamic obstacle avoidance.

Remote Control

WiFi & Bluetooth control mode alongside full autonomous stack for manual override.

Digital Twin (Isaac Sim)

Full HIL simulation — validate code in Isaac Sim before touching real hardware.

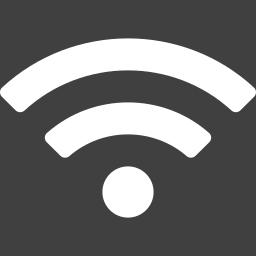
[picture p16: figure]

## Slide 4

EDUCATIONAL VALUE

Working on this project develops expertise across six high-demand engineering disciplines:

Embedded Systems

1. Real-time control via Teensy 4.1
2. PWM motor driving & encoder feedback
3. PID velocity loop tuning
4. CAN / serial communication protocols

Mechanical Design

1. Custom gearbox design & fabrication
2. Shock absorber spring-damper physics
3. Hydraulic brake circuit from scratch
4. FEA – Finite Element Analysis

ROS 2 Software

1. Node-based modular architecture
2. SLAM mapping & localization
3. Nav2 autonomous navigation
4. Sensor fusion & odometry

AI & Computer Vision

1. Neural network object detection
2. AEB depth threshold pipeline
3. Person re-identification & following
4. Edge inference on Jetson GPU

Simulation & Testing

1. NVIDIA Isaac Sim 3D setup
2. Hardware-in-the-loop (HIL)
3. Digital twin validation workflow
4. Sim-to-real transfer techniques

Controls & Comms

1. WiFi / Bluetooth remote control
2. Autonomous ↔ manual mode switching
3. ROS 2 teleop integration
4. Emergency stop & failsafe logic

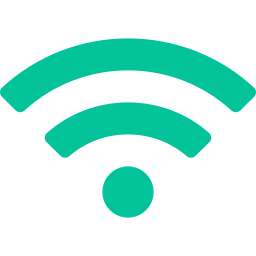
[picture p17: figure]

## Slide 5

COMPONENT COST ESTIMATE

Component

Category

Qty

Unit

Total

NVIDIA Jetson Orin Nano Super

Teensy 4.1 Microcontroller

Compute

Embedded

1

1

$249

$30

$249

$30

Pololu 37D Bare DC Motor (24V, Encoder)

Custom CNC Gearbox (Aluminum, 2-ratio)

Drivetrain

Transmission

4

4

$37.50

~$40

$150

~$160

Servo Motor (Gear Selector)

Transmission

1

$30

$30

Cytron MDD10A Dual Motor Driver

Intel RealSense D435 Camera

Power Elec.

Perception

2

1

$30

$399

$60

$399

RPLIDAR A1 (2D LiDAR)

IMU (BNO055)

Perception

Sensing

1

1

$100

$25

$100

$25

WiFi / Bluetooth Module

LiPo Battery Pack (22.2V 10Ah)

Comms

Power

1

1

$25

$150

$25

$150

Power Management / BMS Board

Robot Chassis (Aluminum Frame)

Power

Structure

1

1

$80

$180

$80

$180

Wiring, Connectors, Misc.

Misc.

—

—

~$1,758

$120

TOTAL ESTIMATED COST

* Custom gearbox cost is estimated for materials. ROS 2 and NVIDIA Isaac Sim are free / open-source.

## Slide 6

PROJECT TIMELINE — Spring · Summer · Fall 2026

SPRING 2026

Now → May 13

SUMMER 2026

May 26 → July 6

FALL 2026

Aug 24 → Dec 16

Procurement — Motors, MCU, Sensors, Battery

3D Print / CNC — Manufacture custom parts

Camera Integration — RealSense + SLAM depth layer

CAD Design — Chassis, Gearbox, Brakes, Shockers

Full Mechanical Assembly — Chassis + all systems

AI Models — YOLO object detection, person following

FEA Analysis — Structural validation of components

Wiring — MCU, LiDAR, IMU, AI PC, BT/WiFi

AEB System — Depth threshold emergency braking

Order & receive all hardware components

Embedded Firmware — Motor control, PID, encoders

Full ROS 2 Stack — Nav2 + sensor fusion on hardware

Testing — Power regen, gearbox, brakes, remote ctrl

System Integration — All subsystems working together

Isaac Sim — Full scale simulation & basic SLAM test

Final Demo — Full autonomous run & documentation

M1

M2

M3

MILESTONE #1 — May 13

Chassis physical · Wheels mounted
Brakes CAD · Shockers CAD · Gearbox CAD

MILESTONE #2 — June 13

Full assembly complete · All wiring done
Gearbox tested · Brakes tested · Remote control · Simulation Testing

MILESTONE #3 — Dec 16 ★

Camera integrated · AI models running
Full autonomous stack on hardware · Final demo

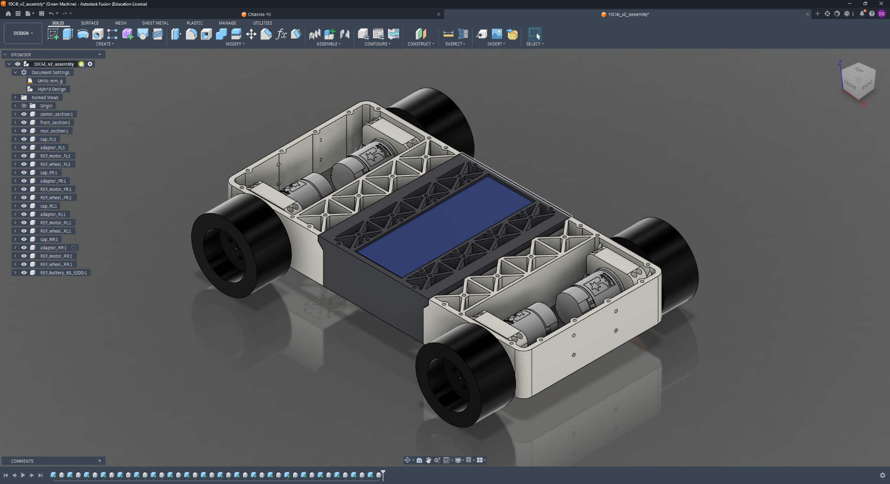
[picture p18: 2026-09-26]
hero.png

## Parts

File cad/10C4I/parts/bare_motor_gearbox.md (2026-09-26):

# Bare-motor 2-stage gearbox ×2 (not modeled yet)

**Status:** the concept and the parts list are settled, but there's **no CAD yet**. It's blocked on measurements of Pololu's pinion (below).

**Why it exists:** two of the four motors are bare Pololu #4690s (24 V, 10,000 RPM free, ~0.55 kg·cm stall) with no gearbox. They need a fixed ~18.75:1 printed reduction so they match the #4691 19:1 gearmotors on the other corners. Mecanum drifts if the corners don't match.

## Concept

```
bare motor ─► Pololu helical pinion ─► [stage 1: printed helical gear ~4.3:1]
                                             │  (intermediate 5 mm hex shaft)
                                             ▼
                                      [stage 2: printed spur pinion → gear ~4.3:1]
                                             │  (output 5 mm hex shaft, through the chassis wall)
                                             ▼
                                        REV hex adapter → wheel
```

- **Why two stages:** a single 18.75:1 stage (10T to 188T) needs a ~94 mm gear. That's bigger than the 75 mm wheel, so it would hit the floor. Two stages of ~4.3:1 keep the largest gear around 43 mm.
- **Stage 1:** a printed helical gear matched to Pololu's pinion. The pinion is permanently fixed to its 2 mm shaft, so keeping it was the only option.
- **Stage 2:** spur gears with bigger teeth, since this stage carries about 4× the torque.
- **Shafts:** both run in REV flanged bearings on 5 mm hex shafts.
- **Load target:** survive Pololu's own gearbox rating, 10 kg·cm continuous and 25 kg·cm in short bursts. Output is ~530 RPM and ~10 kg·cm at stall.
- **Layout (proposed, not confirmed):** both bare motors on the same axle, for example the rear. Then the front end section stays as is, and only the rear becomes a new variant with gearbox mounts.

## Known motor geometry (Pololu #4690/#4750 drawing)

- 6× **M2.5** threaded holes in the face, on a ~26.5 mm circle, **3.5 mm max** depth
- Pinion is 5 mm long and ends 9 mm from the motor face, with an 8 mm boss at the base, on a 2 mm shaft
- Pinion tip diameter is ~6.0 mm per Pololu's CAD, which shows it as a plain cylinder

## Needed before modeling

- [ ] Pinion **tooth count** (mark one tooth)
- [ ] Diameter **across the tooth tips** (calipers)
- [ ] **Helix hand:** with the shaft up, do the teeth lean `/` or `\`?
- [ ] A sharp side photo of the pinion with a ruler in frame (for the helix angle)
- [ ] Confirm both bare motors go on the same axle

## Parts to buy (~$55 from REV)

| Part | Qty needed | Pack | ~Price |
|---|---|---|---|
| 8×12×3.5 flanged bearings (REV-49-1559) | 8 | 10-pack | $18.50 |
| 5 mm hex to 8 mm round bearing inserts (REV-41-1528) | 8 | 20-pack | $11.00 |
| 5 mm × 90 mm hex shaft (cut to length with a Dremel; it's stainless) | 4 | 4-pack | ~$13 |
| Shaft collars (Slim if in stock) + 1.5 mm hex key | as needed | 10-pack | $9.75 |
| Plain nylon (PA12/PA6, **not** CF) for the gears | 50–100 g | spool | $30–50 |
| PTFE grease (Super Lube) | – | – | ~$10 |
| M2.5 screws, motor to housing (length TBD, under 3.5 mm engagement) | 12 | – | – |

Print the gears in plain nylon. Carbon fiber grinds down both the printed teeth and the steel pinion.

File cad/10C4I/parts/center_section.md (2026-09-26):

# Center section ×1

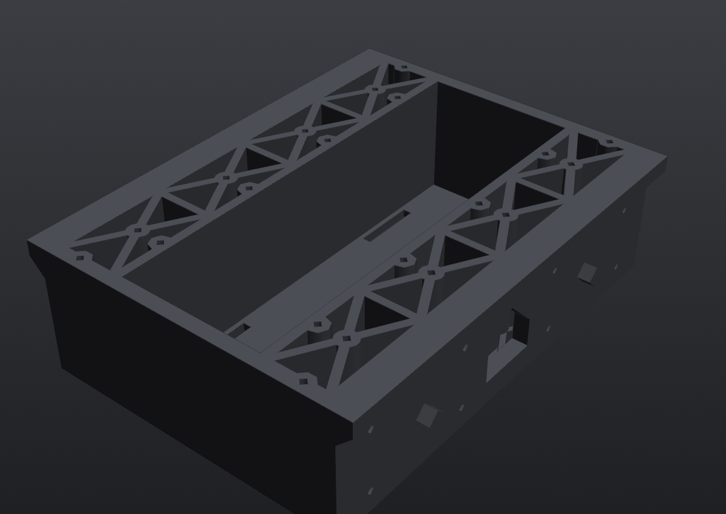
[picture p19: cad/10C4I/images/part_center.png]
center section


**Files:** `step/10C4I_v2_center_section_x1.step`, `stl/10C4I_v2_center_section_x1.stl`. Source is `center_section()` in `src/mini_tesla_10c4i_v2.py`.

**What it does:** the middle third of the chassis. It holds the battery low in a bay and carries the Jetson plate on top. Its lap lips put the center's weight *onto* the end sections instead of hanging it on screws.

| | |
|---|---|
| Print size | 130.7 × 170 × 49 mm (118.7 body + 6 mm lip each end) |
| Orientation | floor on the bed, no supports |
| Walls | floor 3.0, sides 5.5, bulkheads 6.0, ribs 3.0 |

## Features

- **Battery bay:** 56 mm (along X) × full inner width, between two 3.5 mm walls. The 6S pack (156 × 54 × 45) lies crosswise with 1.5 mm to spare lengthwise, so it only goes in one way.
- **Strap slots:** 4 slots, 3.5 × 25 mm, through the floor at x = ±24.5, y = ±45. Two 20 mm velcro straps go around the pack.
- **X-grid strips:** on each side of the bay, 4 X-braced cells (Y breaks at ±40 and 0) with triangular floor windows. This is the cross-grid look from the reference photo, and it also acts as the bending structure.
- **Lap lips:** a 6 mm lip at the top of each end overhangs onto the end section's bulkhead. The underside is 45°, so it prints without support.
- **Diamond pegs:** 2 per end (y = ±45, z = 20, 4 mm "radius", 5 mm long) for alignment and shear.
- **Joint inserts:** 8 horizontal M2.5 inserts per bulkhead at y = ±25 and ±70, z = 8 and 32. The screws come in from the end-section side.
- **Cable window:** a pentagon through each bulkhead (24 mm wide, z = 9 to 32) for motor and encoder cables.
- **Top mount points:** 20 full-height Ø8 columns with M2.5 inserts at the top face (z = 49):
  - 8 on the X-grid nodes
  - 8 along the bay edges (x = ±32, y = ±20 and ±60), so a plate can bridge over the pack
  - 4 on the side walls at x = ±45 (kept clear of the bay)

Exact coordinates are in [`../mount_points/10C4I_mount_points.csv`](../mount_points/10C4I_mount_points.csv).

## Hardware on this part

- 16× M2.5 inserts (joints)
- up to 20× M2.5 inserts (top mounts, as needed)
- 2× velcro straps

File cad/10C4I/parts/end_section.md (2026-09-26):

# End section ×2 (front and rear are the same part)

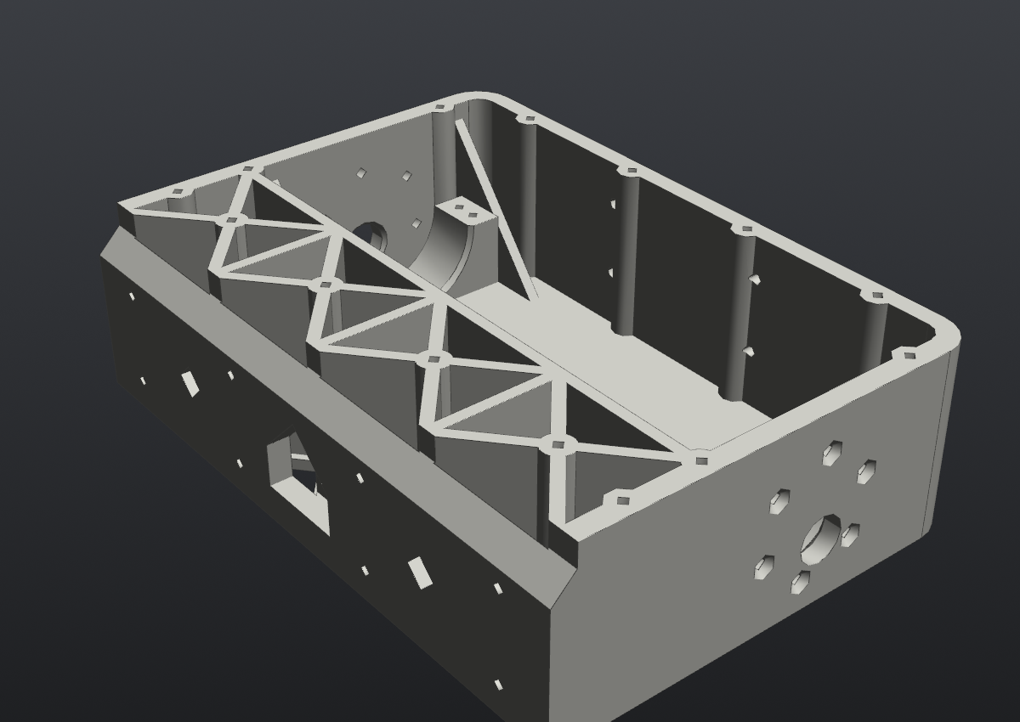
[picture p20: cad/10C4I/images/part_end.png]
end section


**Files:** `step/10C4I_v2_end_section_x2.step`, `stl/10C4I_v2_end_section_x2.stl`. Source is `end_section()`. The rear is the same part rotated 180°.

**What it does:** holds two motors each, carries the wheels, and forms the bumpers.

| | |
|---|---|
| Print size | 118.7 × 170 × 49 mm |
| Orientation | floor on the bed, no supports |
| Walls | floor 3.0, sides 5.5, joint bulkhead 6.0, bumper wall 5.0, R10 outer corners at the bumper |

In the part's own frame, x = 0 is the joint face and x = 118.7 is the bumper face.

## Motor mount (×2 per part)

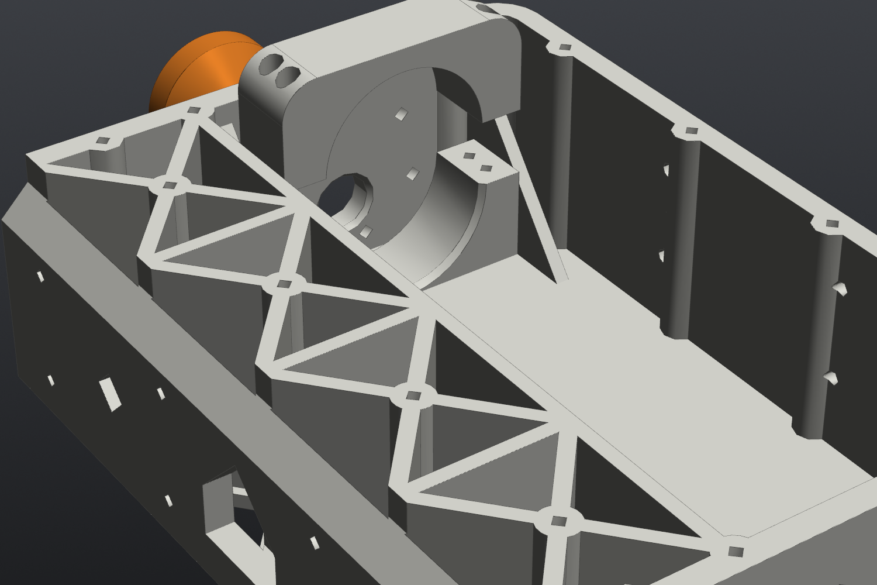
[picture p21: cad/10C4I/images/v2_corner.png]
motor corner


- **Axle** at x = 73.7, z = 16.5 above the underside. That gives 21 mm ground clearance on 75 mm wheels.
- **Wall face:** a Ø12.3 hole for the gearbox bushing with a lead-in chamfer inside, plus 6× Ø3.4 holes for M3 on Pololu's 31 mm circle, countersunk (Ø6.4, 90°) from outside so the flat heads sit flush.
- **Clocking:** the gearbox centre sits 2.39 mm along X and 6.58 mm above the shaft. The motor is rotated so the encoder cable tab clears the floor. Face holes were checked against Pololu's STEP: within 0.02 mm.
- **Clamp saddle:** a Ø37.2 half-bore that grips the **gearbox** (Ø36.8), 3 to 19 mm in from the face. 4 vertical M2.5 inserts per saddle for the [motor cap](motor_cap.md).
  - It clamps the gearbox, not the can, on purpose: the can (Ø34.8) and encoder (Ø34.0) pass through the bore, so the motor can drop in ~22 mm inboard and slide out into place.
  - There's also a lead-in chamfer on the inboard end of the bore.
- **Gussets:** 3 mm triangles on both sides of each saddle tie the side wall to the floor.
- There's no centre rib between the two motors, because it would sit in their install path.

## Joint side

- **45° notch** that the center section's lap lip rests in (0.25 mm clearance)
- **2 diamond peg sockets** (0.25 mm clearance)
- **8× Ø3.0 clearance holes** for M2.5×10, driven from inside this section into the center's inserts
- **Cable window**, matching the center section's

## Electronics zone

The zone between the joint bulkhead and a divider at x = 40 has an X-grid with 4 cells and floor windows, like the center section.

## Mount points

- **Top face:** 14 M2.5 inserts on full-height Ø8 columns: 4 X-grid nodes, 6 on the side walls (none above the gearboxes), and 4 along the bumper
- **Bumper face:** a 2×2 pattern of horizontal M2.5 inserts at y = ±25, z = 18 and 38, for the D435 or another front sensor bracket

## Hardware on this part (each)

- 8× M2.5 inserts (clamp saddles)
- up to 18× M2.5 inserts (mounts)
- 12× M3×8 countersunk (motor faces)
- 8× M2.5×10 (joint)

> **Heads-up:** this part only fits the geared #4691. Two corners are getting bare #4690 motors with a printed gearbox, so one end section will need a new variant. See [bare_motor_gearbox.md](bare_motor_gearbox.md).

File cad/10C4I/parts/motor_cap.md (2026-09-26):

# Motor cap ×4

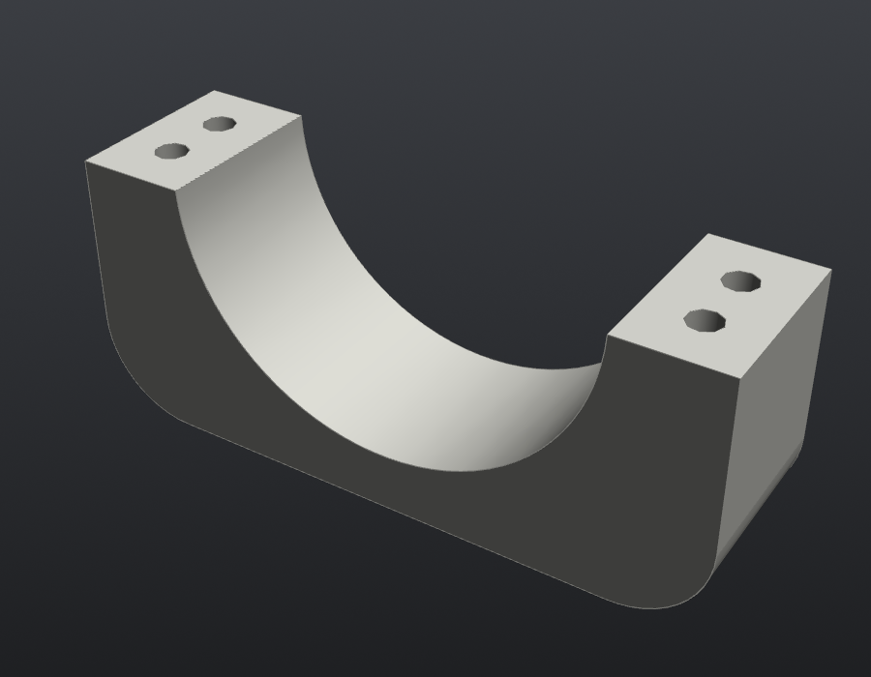
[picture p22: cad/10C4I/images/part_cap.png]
motor cap


**Files:** `step/10C4I_v2_motor_cap_x4.step`, `stl/10C4I_v2_motor_cap_x4.stl`. Source is `motor_cap()`.

**What it does:** the top half of the gearbox clamp. With the M3 face screws, it turns the wheel's bending load into a force couple, so the motor isn't cantilevered off six small screws. Don't skip it.

| | |
|---|---|
| Print size | 56 × 16 × 22.8 mm |
| Orientation | flat top on the bed (exported that way) |
| Bore | Ø37.2 over the Ø36.8 gearbox |
| Clamp gap | 0.8 mm. The cap sits this high so the screws actually squeeze the gearbox |

## Features

- 4× Ø2.9 clearance holes for M2.5, at ±23.3 mm from the gearbox centre, 8 and 14 mm in from the motor face
- Ø5.0 counterbores so the screw heads sit below the top
- R8 fillets on the top edges

The same part works for all four corners.

## Hardware (each)

- 4× M2.5×16 socket head into the saddle inserts in the end section

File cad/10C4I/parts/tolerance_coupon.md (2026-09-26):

# Tolerance coupon ×1 (print this first)

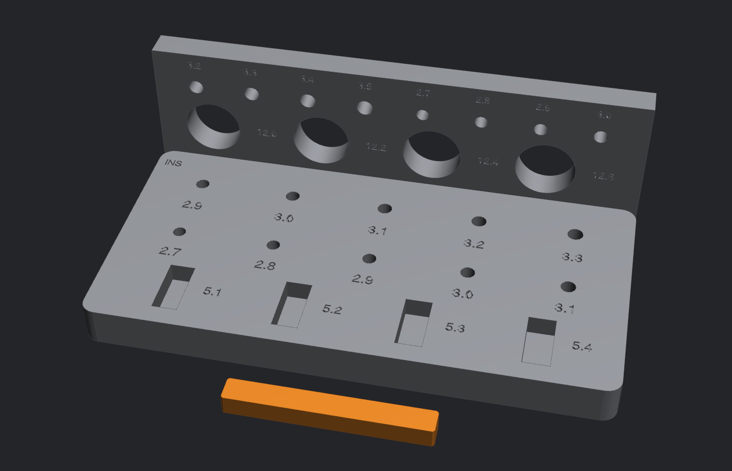
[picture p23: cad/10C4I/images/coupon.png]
coupon


**Files:** `step/10C4I_tolerance_coupon.step`, `stl/10C4I_tolerance_coupon.stl`. Source is `src/tolerance_coupon.py`.

**What it does:** every printer makes holes a little differently. This coupon finds the real numbers for *your* printer and filament before you spend a kilo of PA612-CF on the chassis. Print it with the **same filament and settings** as the chassis.

| | |
|---|---|
| Size | 104 × 70.5 × 34 mm (plate + standing wall + loose key bar) |
| Orientation | as exported. The wall prints its holes sideways, the same way the motor walls do |

## What it tests

| Row | Sizes (mm) | Feeds script variable |
|---|---|---|
| Plate: M2.5 insert holes (blind 6.5 mm) | 2.9 / 3.0 / 3.1 / 3.2 / 3.3 | `INS_M25` (**most important**) |
| Plate: M2.5 clearance, vertical | 2.7 / 2.8 / 2.9 / 3.0 / 3.1 | `CLR_M25_V` |
| Plate: slots for the 5.00 mm key | 5.1 / 5.2 / 5.3 / 5.4 | `SLIDE` |
| Wall: gearbox bushing | 12.0 / 12.2 / 12.4 / 12.6 | `BUSH_D` |
| Wall: M3 clearance, horizontal | 3.2 / 3.3 / 3.4 / 3.5 | `CLR_M3_H` |
| Wall: M2.5 clearance, horizontal | 2.7 / 2.8 / 2.9 / 3.0 | `CLR_M25_H` |

## How to read it

1. **Insert row:** heat-press one insert into each hole. The winner goes in with light pressure from the iron, ends up flush and straight, and doesn't spin when you tighten a screw into it.
2. **Screw rows:** pick the smallest hole the screw slides through cleanly.
3. **Bushing:** pick the one the gearbox bushing slips into without slop.
4. **Slots:** pick the slot the key slides in with no wobble.

Then update the variables in `src/mini_tesla_10c4i_v2.py`, re-run it, and every hole on the robot updates.

## Results

| Test | Best size | Date |
|---|---|---|
| Insert | _not tested yet_ | |
| M2.5 vertical | _not tested yet_ | |
| M2.5 horizontal | _not tested yet_ | |
| M3 horizontal | _not tested yet_ | |
| Bushing | _not tested yet_ | |
| Key slot | _not tested yet_ | |

## History

The first coupon's insert row ran 3.4 to 4.2 mm, sized for the common ~4 mm-OD inserts. It was re-cut to 2.9 to 3.3 once the actual inserts turned out to be 3.5 mm OD. If you printed a coupon before that, reprint it.

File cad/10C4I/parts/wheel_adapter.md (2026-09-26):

# Wheel adapter ×4

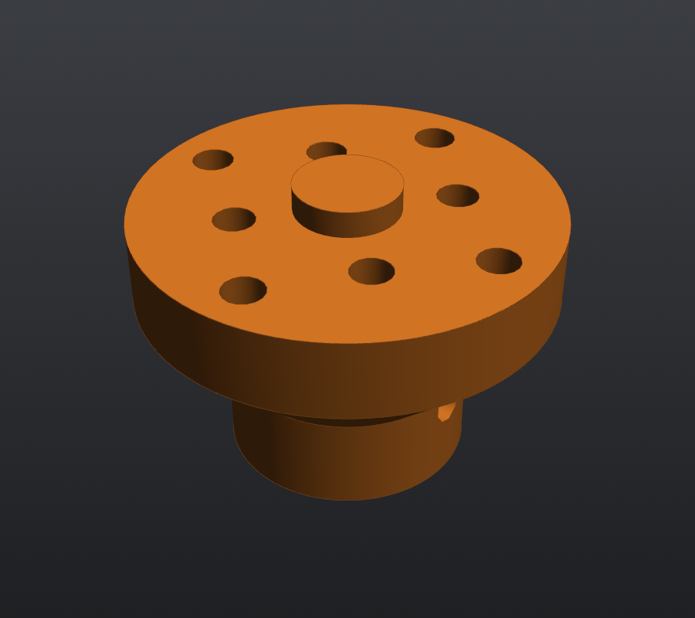
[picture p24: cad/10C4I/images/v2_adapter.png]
wheel adapter


**Files:** `step/10C4I_v2_wheel_adapter_x4.step`, `stl/10C4I_v2_wheel_adapter_x4.stl`. Source is `wheel_adapter()`.

**What it does:** connects the Pololu 6 mm D-shaft to a REV DUO 75 mm mecanum wheel. REV ships 5 mm hex adapters, which don't fit a D-shaft, so this replaces them.

| | |
|---|---|
| Print size | Ø31 × 21.7 mm |
| Orientation | hub end on the bed (exported that way) |
| Position | starts 8.0 mm from the gearbox face (2.5 mm off the wall); the wheel-side face is at 27.7 mm |

## Features

- **Hub:** Ø18, then a 45° cone into a Ø31 × 6 mm flange, so it prints with no overhang.
- **D-bore:** Ø6.15 with the flat at 2.45 mm from centre, 14.6 mm deep, with a lead-in chamfer.
- **Set screw:** a radial M2.5 insert, 6 mm up from the hub end, lands on the shaft's flat.
- **Pilot:** a Ø7.8 × 2 mm boss that centres the wheel in its Ø8.1 bore.
- **8× M2.5 inserts** in the flange face, 5.5 mm deep:
  - 4 on the wheel's 24 mm circle (its Ø4.0 holes)
  - 4 on its 16 mm circle (its Ø3.0 holes), rotated 45°

REV's hole pattern was measured from the REV-41-1656 drawing. The 16 mm circle matches REV's published pattern.

## History

The first v2 adapter used 4 printed dowels in the 3.0 mm holes plus 4 screws. It was changed to 8 inserts for a more secure, repeatable connection.

## Hardware (each)

- 9× M2.5 inserts (8 face + 1 set screw)
- 8× M2.5×6 socket head
- 1× M2.5×6 cup-point set screw

## Watch out

- The D-bore is the part most likely to wear. If a wheel starts slipping, the upgrade is a metal hub.
- **Print one and test-fit it in a wheel first.** The inside of the REV hub cup couldn't be measured from the drawing.
- On the two bare-motor corners, the gearbox output will be a 5 mm hex shaft. Those wheels use REV's own hex adapters, not this part.

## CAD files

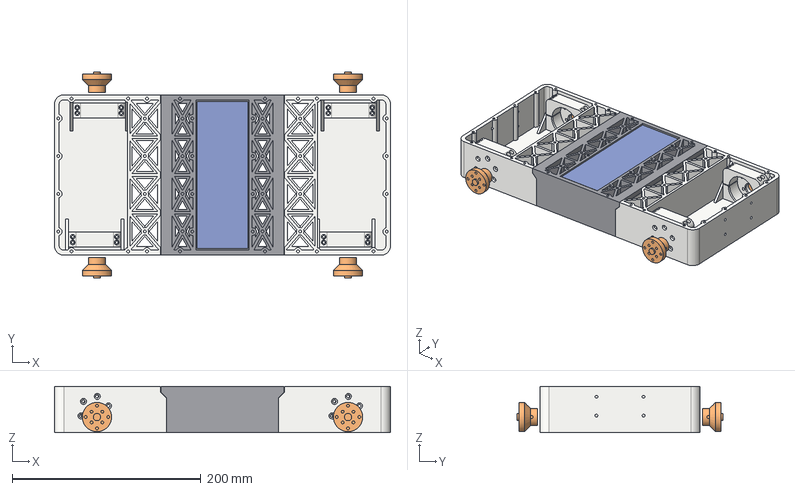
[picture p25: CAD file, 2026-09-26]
cad/10C4I/step/10C4I_v2_assembly.step
356.1 x 218.4 x 49.0 mm
center_section
front_section
rear_section
cap_FL
adapter_FL
cap_FR
adapter_FR
cap_RL
adapter_RL
cap_RR
adapter_RR
REF_battery_6S_5200

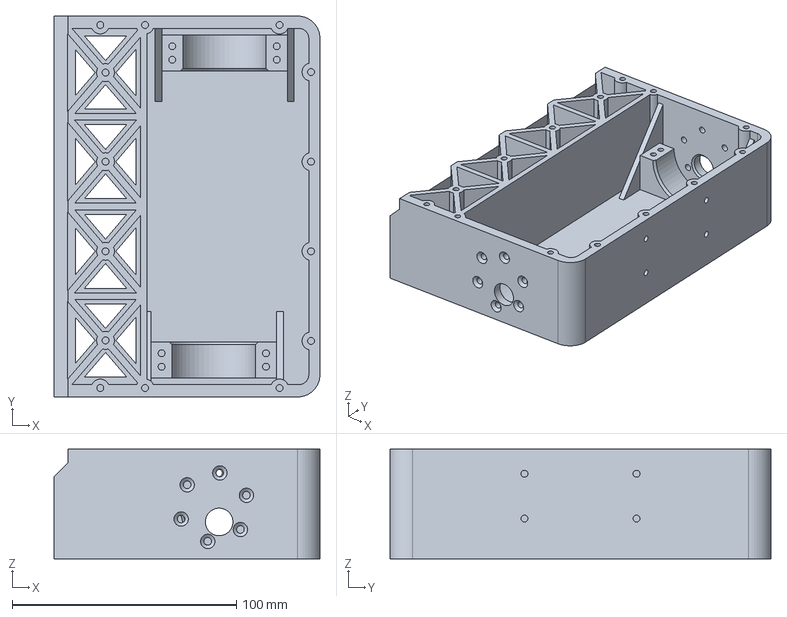
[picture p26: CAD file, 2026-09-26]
cad/10C4I/step/10C4I_v2_end_section_x2.step
118.7 x 170.0 x 49.0 mm

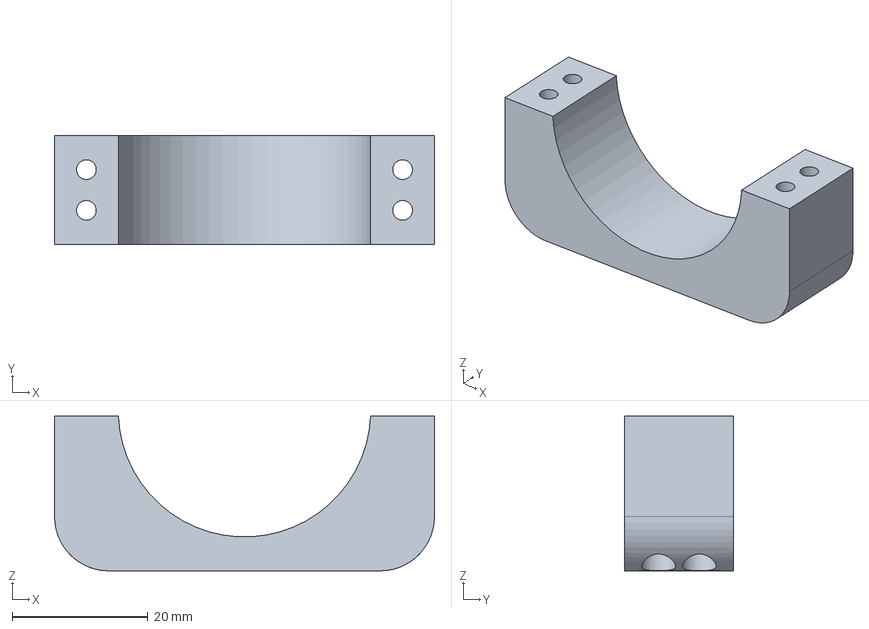
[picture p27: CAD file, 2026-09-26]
cad/10C4I/step/10C4I_v2_motor_cap_x4.step
56.0 x 16.0 x 22.8 mm

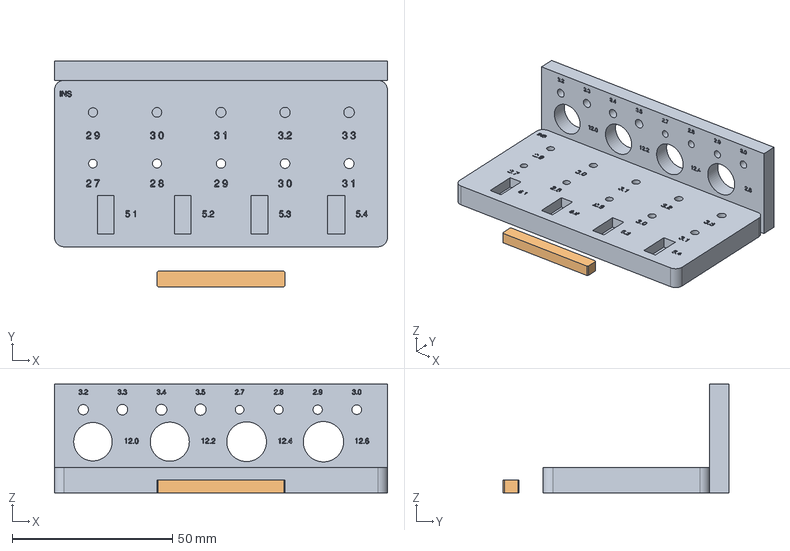
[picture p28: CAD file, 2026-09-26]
cad/10C4I/step/10C4I_tolerance_coupon.step
104.0 x 70.5 x 34.0 mm

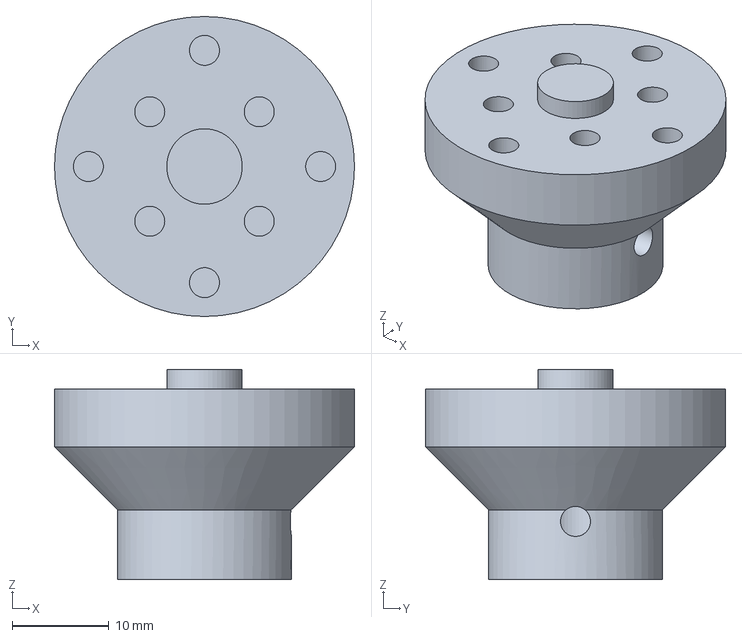
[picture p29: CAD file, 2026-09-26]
cad/10C4I/step/10C4I_v2_wheel_adapter_x4.step
31.0 x 31.0 x 21.7 mm

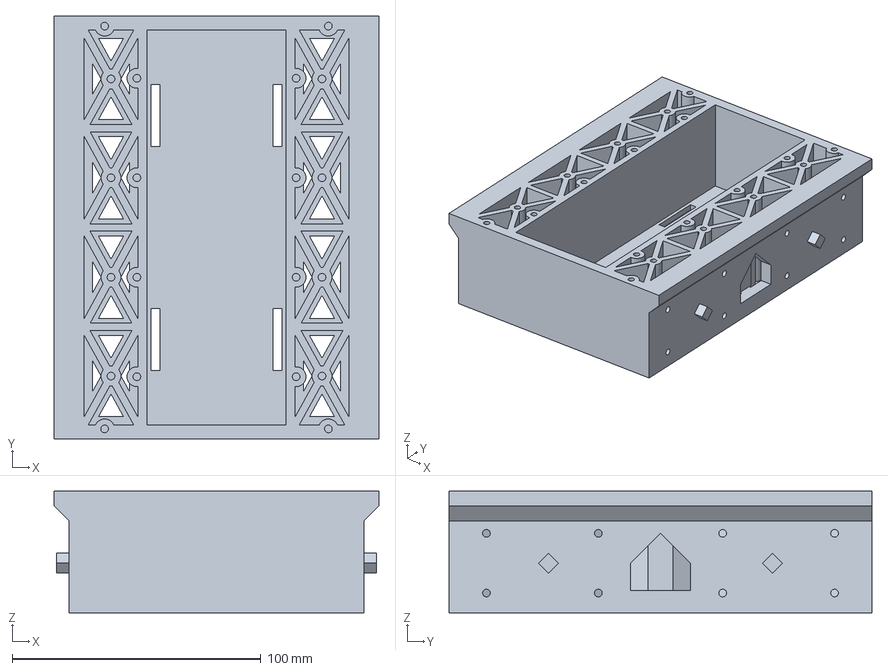
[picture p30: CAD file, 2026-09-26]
cad/10C4I/step/10C4I_v2_center_section_x1.step
130.7 x 170.0 x 49.0 mm

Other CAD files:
cad/10C4I/stl/10C4I_tolerance_coupon.stl
cad/10C4I/stl/10C4I_v2_center_section_x1.stl
cad/10C4I/stl/10C4I_v2_end_section_x2.stl
cad/10C4I/stl/10C4I_v2_motor_cap_x4.stl
cad/10C4I/stl/10C4I_v2_wheel_adapter_x4.stl

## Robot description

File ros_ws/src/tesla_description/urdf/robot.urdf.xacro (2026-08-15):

<?xml version="1.0"?>

<robot xmlns:xacro="http://www.ros.org/wiki/xacro" name="simple_bot">

    <!-- =========================
         COLORS
    ========================== -->

    <material name="blue">
        <color rgba="0.1 0.3 0.8 1.0"/>
    </material>

    <material name="black">
        <color rgba="0.05 0.05 0.05 1.0"/>
    </material>


    <!-- =========================
         BASE FOOTPRINT
    ========================== -->

    <link name="base_footprint"/>

    <joint name="base_footprint_joint" type="fixed">
        <parent link="base_footprint"/>
        <child link="base_link"/>
        <origin xyz="0 0 0.10" rpy="0 0 0"/>
    </joint>


    <!-- =========================
         ROBOT BODY
    ========================== -->

    <link name="base_link">

        <visual>
            <origin xyz="0 0 0"/>
            <geometry>
                <box size="0.40 0.30 0.15"/>
            </geometry>
            <material name="blue"/>
        </visual>

        <collision>
            <origin xyz="0 0 0"/>
            <geometry>
                <box size="0.40 0.30 0.15"/>
            </geometry>
        </collision>

        <inertial>
            <origin xyz="0 0 0"/>
            <mass value="5.0"/>
            <inertia ixx="0.0469" ixy="0.0" ixz="0.0" iyy="0.0833" iyz="0.0" izz="0.1302"/>
        </inertial>

    </link>


    <!-- =========================
         LEFT WHEEL
    ========================== -->

    <link name="left_wheel_link">

        <visual>
            <origin xyz="0 0 0" rpy="1.5708 0 0"/>
            <geometry>
                <cylinder radius="0.08" length="0.04"/>
            </geometry>
            <material name="black"/>
        </visual>

        <collision>
            <origin xyz="0 0 0" rpy="1.5708 0 0"/>
            <geometry>
                <cylinder radius="0.08" length="0.04"/>
            </geometry>
        </collision>

        <inertial>
            <mass value="0.5"/>
            <inertia ixx="0.001" ixy="0.0" ixz="0.0" iyy="0.001" iyz="0.0" izz="0.001"/>
        </inertial>

    </link>

    <joint name="left_wheel_joint" type="continuous">

        <parent link="base_link"/>
        <child link="left_wheel_link"/>

        <origin xyz="0 0.17 -0.02" rpy="0 0 0"/>

        <axis xyz="0 1 0"/>

    </joint>


    <!-- =========================
         RIGHT WHEEL
    ========================== -->

    <link name="right_wheel_link">

        <visual>
            <origin xyz="0 0 0" rpy="1.5708 0 0"/>
            <geometry>
                <cylinder radius="0.08" length="0.04"/>
            </geometry>
            <material name="black"/>
        </visual>

        <collision>
            <origin xyz="0 0 0" rpy="1.5708 0 0"/>
            <geometry>
                <cylinder radius="0.08" length="0.04"/>
            </geometry>
        </collision>

        <inertial>
            <mass value="0.5"/>
            <inertia ixx="0.001" ixy="0.0" ixz="0.0" iyy="0.001" iyz="0.0" izz="0.001"/>
        </inertial>

    </link>

    <joint name="right_wheel_joint" type="continuous">

        <parent link="base_link"/>
        <child link="right_wheel_link"/>

        <origin xyz="0 -0.17 -0.02" rpy="0 0 0"/>

        <axis xyz="0 1 0"/>

    </joint>


    <!-- =========================
         CASTER
    ========================== -->

    <link name="caster_link">

        <visual>
            <geometry>
                <sphere radius="0.04"/>
            </geometry>
            <material name="black"/>
        </visual>

        <collision>
            <geometry>
                <sphere radius="0.04"/>
            </geometry>
        </collision>

        <inertial>
            <mass value="0.1"/>
            <inertia ixx="0.0001" ixy="0" ixz="0" iyy="0.0001" iyz="0" izz="0.0001"/>
        </inertial>

    </link>

    <joint name="caster_joint" type="fixed">

        <parent link="base_link"/>
        <child link="caster_link"/>

        <origin xyz="-0.15 0 -0.075"/>

    </joint>


    <!-- =========================
         LIDAR
    ========================== -->

    <link name="lidar_link">

        <visual>
            <geometry>
                <cylinder radius="0.045" length="0.04"/>
            </geometry>
            <material name="black"/>
        </visual>

    </link>

    <joint name="lidar_joint" type="fixed">

        <parent link="base_link"/>
        <child link="lidar_link"/>

        <origin xyz="0.08 0 0.115"/>

    </joint>


</robot>

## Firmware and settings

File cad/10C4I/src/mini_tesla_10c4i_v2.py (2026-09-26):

"""
Mini Tesla 10C4I - chassis v2 (built around the real parts)

Parts (print qty):
  center_section  x1  battery bay + X-grid strips          (floor on bed)
  end_section     x2  front AND rear are the same part      (floor on bed)
  motor_cap       x4  top half of each can clamp            (flat top on bed)
  wheel_adapter   x4  6 mm D-shaft -> REV DUO 75 mm wheel, 8x M2.5 inserts (hub end on bed)

Real parts used:
  Pololu #4691 19:1 37D gearmotor w/ encoder (STEP from Pololu)
  REV DUO 75 mm mecanum (REV-41-1656/1657): web holes 4x 4.0 on 24 BC, 4x 3.0 on 16 BC, 8.1 bore
  Turnigy 6S 5200 mAh: 156 x 54 x 45

Fasteners: M3 countersunk only at the motor faces (Pololu thread depth max 3.0 mm),
           M2.5 + heat-set inserts everywhere else.
Coordinates: X forward, Y left, Z up. Z = 0 is the chassis underside. mm.
"""
import math, os
import numpy as np
import cadquery as cq
from shapely.geometry import Polygon

# =============================================================================
# 1. TOLERANCES  <-- update these from the coupon, then re-run
# =============================================================================
INS_M25   = 3.1    # M2.5 heat-set pilot hole (Pofsnnx M2.5 x 4 x 3.5 OD). Coupon will confirm.
INS_DEPTH = 6.0    # blind depth for inserts
CLR_M25_V = 2.9    # M2.5 clearance, hole axis vertical in print
CLR_M25_H = 3.0    # M2.5 clearance, hole axis horizontal in print
CLR_M3_H  = 3.4    # M3 clearance through the motor walls (horizontal in print)
CSK_M3_D  = 6.4    # 90 deg countersink for M3 flat heads (flush, wheel is 3 mm away)
BUSH_D    = 12.3   # gearbox bushing (12.0 nominal)
SLIDE     = 0.25   # per-side clearance on pegs / lap joint
GB_BORE   = 36.8 + 0.4   # clamp bore over the gearbox housing
CLAMP_GAP = 0.8    # cap sits this high so the screws actually clamp the can
DBORE_D, DFLAT = 6.15, 2.45        # 6 mm D-shaft (flat at 2.4 from centre)
PILOT_D = 7.8                      # centres the wheel in its 8.1 bore

# =============================================================================
# 2. LAYOUT
# =============================================================================
BED = (250.0, 210.0, 220.0)          # Prusa MK4S
L_S   = 118.7        # every section is the same length (356 total ~ 16" MacBook Pro)
W     = 170.0        # body width (battery rides crosswise inside)
H     = 49.0         # box height; everything tucks under this plane
GROUND = 21.0        # floor underside to ground
FLOOR, SIDE_T, BULK_T, END_T, RIB_T = 3.0, 5.5, 6.0, 5.0, 3.0
HX = L_S / 2         # centre-section half length
Y_IN = W / 2 - SIDE_T

# Wheel (REV DUO 75 mm)
WHEEL_R, WHEEL_RMAX, WHEEL_W, WHEEL_WEB, WEB_T = 37.5, 39.0, 40.8, 19.2, 2.4
WHEEL_GAP = 3.0
AXLE_Z = WHEEL_R - GROUND
AXLE_XL = L_S - 45.0            # axle x in end-section local coords (x=0 at joint face)

# Motor (Pololu 37D 19:1 + encoder), clocked so the encoder cable tab clears the floor
MOTOR_L, GB_L, CAN_R, GB_R = 67.6, 21.5, 17.4, 18.4
GB_DX, GB_DZ = 2.39, 6.58      # gearbox centre relative to shaft (left motor; right = -dx)
FACE_BC_R = 15.5
MOTOR_CZ = AXLE_Z + GB_DZ

# Motor clamp: grips the GEARBOX right behind the wall. The can/encoder (34.8/34.0) pass through the
# 37.2 bore, so the motor can slide in axially and the bushing drops into the wall hole.
SAD_U = (3.0, 19.0)            # distance from gearbox face (gearbox is 21.5 long)
SAD_HW = 28.0
CAP_TOP = MOTOR_CZ + GB_BORE / 2 + 5.0
CAP_BOLT_DX = 23.3

# Battery bay
BATT = (156.0, 54.0, 45.0)
BAY_IN = BATT[1] + 2.0         # along X
BAY_T = 3.5

# Joint
LIP = 6.0                                   # centre lip over end bulkhead
LIP_Z0 = H - 12.0                           # 45 deg underside starts here
PEG_Y, PEG_Z, PEG_R, PEG_L = 45.0, 20.0, 4.0, 5.0
JOINT_SCREWS = [(y, z) for z in (8.0, 32.0) for y in (-70.0, -25.0, 25.0, 70.0)]

# =============================================================================
# helpers
# =============================================================================
def box(x0, x1, y0, y1, z0, z1):
    return cq.Workplane("XY").box(x1 - x0, y1 - y0, z1 - z0, centered=False).translate((x0, y0, z0))

def cyl_x(x0, x1, y, z, d):
    return cq.Workplane("YZ").workplane(offset=x0).center(y, z).circle(d / 2).extrude(x1 - x0)

def cyl_y(y0, y1, x, z, d):
    return cq.Workplane("XZ").workplane(offset=-y0).center(x, z).circle(d / 2).extrude(-(y1 - y0))

def cyl_z(z0, z1, x, y, d):
    return cq.Workplane("XY").workplane(offset=z0).center(x, y).circle(d / 2).extrude(z1 - z0)

def cone(p0, direction, d0, d1, h):
    return cq.Workplane("XY").add(cq.Solid.makeCone(d0 / 2, d1 / 2, h, cq.Vector(*p0), cq.Vector(*direction)))

def prism_xz(pts, y0, y1):
    return cq.Workplane("XZ").workplane(offset=-y0).polyline(pts).close().extrude(-(y1 - y0))

def prism_yz(pts, x0, x1):
    return cq.Workplane("YZ").workplane(offset=x0).polyline(pts).close().extrude(x1 - x0)

def prism_xy(pts, z0, z1):
    return cq.Workplane("XY").workplane(offset=z0).polyline(pts).close().extrude(z1 - z0)

def diamond(cy, cz, r):
    return [(cy, cz - r), (cy + r, cz), (cy, cz + r), (cy - r, cz)]

def rib_between(x0, y0, x1, y1, z0, z1, clip):
    L = math.hypot(x1 - x0, y1 - y0) + RIB_T
    a = math.degrees(math.atan2(y1 - y0, x1 - x0))
    r = (cq.Workplane("XY").box(L, RIB_T, z1 - z0, centered=(True, True, False))
         .rotate((0, 0, 0), (0, 0, 1), a).translate(((x0 + x1) / 2, (y0 + y1) / 2, z0)))
    return r.intersect(clip)

def x_cell(x0, x1, y0, y1, z0, z1):
    """X-braced cell: two diagonal ribs clipped to the cell."""
    clip = box(x0, x1, y0, y1, z0, z1)
    return (rib_between(x0, y0, x1, y1, z0, z1, clip)
            .union(rib_between(x0, y1, x1, y0, z0, z1, clip)))

def x_windows(x0, x1, y0, y1, web=RIB_T / 2 + 2.0):
    """The four triangular floor windows of an X cell, inset so ribs keep a solid footing."""
    cx, cy = (x0 + x1) / 2, (y0 + y1) / 2
    corners = [(x0, y0), (x1, y0), (x1, y1), (x0, y1)]
    cut = None
    for i in range(4):
        tri = Polygon([corners[i], corners[(i + 1) % 4], (cx, cy)]).buffer(-web, join_style=2)
        if tri.is_empty or tri.area < 20:
            continue
        pts = list(tri.exterior.coords)[:-1]
        w = prism_xy(pts, -1, FLOOR + 1)
        cut = w if cut is None else cut.union(w)
    return cut

def top_boss(x, y, z_top=H, d=8.0):
    return cyl_z(0.0, z_top, x, y, d)          # full-height column: no overhang, ties floor to top

def top_ins(x, y, z_top=H):
    return cyl_z(z_top - INS_DEPTH, z_top + 1, x, y, INS_M25)

# =============================================================================
# CENTER SECTION  (world coords)
# =============================================================================
def center_section():
    bay_o = BAY_IN / 2 + BAY_T
    body = box(-HX, HX, -W / 2, W / 2, 0, H).cut(
        box(-HX + BULK_T, HX - BULK_T, -Y_IN, Y_IN, FLOOR, H + 1))
    # battery bay walls
    for s in (-1, 1):
        body = body.union(box(*sorted((s * BAY_IN / 2, s * bay_o)), -Y_IN, Y_IN, 0, H))
    # X-grid strips between bay and bulkheads
    ycells = [-Y_IN, -40.0, 0.0, 40.0, Y_IN]
    nodes = []
    for s in (-1, 1):
        xa, xb = sorted((s * bay_o, s * (HX - BULK_T)))
        for y in ycells[1:-1]:
            body = body.union(box(xa, xb, y - RIB_T / 2, y + RIB_T / 2, 0, H))
        for y0, y1 in zip(ycells[:-1], ycells[1:]):
            body = body.union(x_cell(xa, xb, y0, y1, 0, H))
            body = body.cut(x_windows(xa, xb, y0, y1))
            nodes.append(((xa + xb) / 2, (y0 + y1) / 2))
    # lap lips (45 deg underside -> prints without support)
    for s in (-1, 1):
        pts = [(s * HX, LIP_Z0), (s * (HX + LIP), LIP_Z0 + LIP), (s * (HX + LIP), H), (s * HX, H)]
        body = body.union(prism_xz(pts, -W / 2, W / 2))
        # diamond alignment pegs
        for py in (-PEG_Y, PEG_Y):
            xa, xb = sorted((s * (HX - 1), s * (HX + PEG_L)))
            peg = prism_yz(diamond(py, PEG_Z, PEG_R), xa, xb)
            body = body.union(peg)
    # top mounting bosses (M2.5 inserts)
    tops = []
    for x in (-45.0, 45.0):                       # not inside the bay: the pack is 156 of 159 mm
        for s in (-1, 1):
            tops.append((x, s * (W / 2 - 4.0)))
    for s in (-1, 1):
        for y in (-60.0, -20.0, 20.0, 60.0):
            tops.append((s * (BAY_IN / 2 + 4.0), y))
    tops += nodes
    for (x, y) in tops:
        body = body.union(top_boss(x, y))
    for (x, y) in tops:
        body = body.cut(top_ins(x, y))
    # joint: inserts in the centre bulkheads, screws come from the end sections
    for s in (-1, 1):
        xa, xb = sorted((s * (HX - BULK_T - 1), s * (HX + 1)))
        for (y, z) in JOINT_SCREWS:
            body = body.cut(cyl_x(xa, xb, y, z, INS_M25))
        body = body.cut(cable_window(s * (HX - BULK_T - 1), s * (HX + 1)))
    # battery strap slots (2 straps across the pack)
    for sy in (-1, 1):
        for sx in (-1, 1):
            xs = sx * (BAY_IN / 2 - 3.5)
            body = body.cut(box(xs - 1.75, xs + 1.75, sy * 45 - 12.5, sy * 45 + 12.5, -1, FLOOR + 1))
    return body, tops

def cable_window(xa, xb):
    xa, xb = sorted((xa, xb))
    pts = [(-12.0, 9.0), (12.0, 9.0), (12.0, 20.0), (0.0, 32.0), (-12.0, 20.0)]
    return prism_yz(pts, xa, xb)

# =============================================================================
# MOTOR GEOMETRY (end-section local coords)
# =============================================================================
def motor_frame(s):
    """s=+1 left motor (shaft +Y), s=-1 right. Returns gearbox centre (x,z), face y, shaft dir angle."""
    gx = AXLE_XL + s * GB_DX
    return gx, MOTOR_CZ, s * Y_IN

def face_holes(s):
    gx, gz, _ = motor_frame(s)
    th_s = math.atan2(AXLE_Z - gz, AXLE_XL - gx)          # gearbox centre -> shaft
    return [(gx + FACE_BC_R * math.cos(th_s + math.radians(30 + 60 * k)),
             gz + FACE_BC_R * math.sin(th_s + math.radians(30 + 60 * k))) for k in range(6)]

# =============================================================================
# END SECTION  (local coords: x=0 joint face, x=L_S bumper face)
# =============================================================================
def end_section():
    body = box(0, L_S, -W / 2, W / 2, 0, H).edges("|Z and >X").fillet(10)
    inner = box(BULK_T, L_S - END_T, -Y_IN, Y_IN, FLOOR, H + 1).edges("|Z and >X").fillet(10 - SIDE_T)
    body = body.cut(inner)

    free_x1 = 40.0
    # divider between the electronics/X-grid zone and the motor strip
    body = body.union(box(free_x1 - RIB_T / 2, free_x1 + RIB_T / 2, -Y_IN, Y_IN, 0, H))
    # X-grid zone
    ycells = [-Y_IN, -40.0, 0.0, 40.0, Y_IN]
    nodes = []
    for y in ycells[1:-1]:
        body = body.union(box(BULK_T, free_x1, y - RIB_T / 2, y + RIB_T / 2, 0, H))
    for y0, y1 in zip(ycells[:-1], ycells[1:]):
        body = body.union(x_cell(BULK_T, free_x1, y0, y1, 0, H))
        body = body.cut(x_windows(BULK_T, free_x1, y0, y1))
        nodes.append(((BULK_T + free_x1) / 2, (y0 + y1) / 2))
    # (no centre rib here: each motor slides ~22 mm inboard during install)

    for s in (-1, 1):
        gx, gz, yf = motor_frame(s)
        ya, yb = sorted((s * (Y_IN - SAD_U[1]), s * (Y_IN - SAD_U[0])))
        body = body.union(box(gx - SAD_HW, gx + SAD_HW, ya, yb, FLOOR - 0.01, gz))
        # gussets: side wall -> floor, flanking the saddle
        for dx in (-1, 1):
            xg = gx + dx * (SAD_HW + 1.5)
            pts = [(s * (Y_IN + 0.5), 0), (s * (Y_IN + 0.5), H - 4), (s * (Y_IN - SAD_U[1] - 16.0), 0)]
            body = body.union(prism_yz(pts, xg - 1.5, xg + 1.5))

    # top mounting bosses
    tops = [(n[0], n[1]) for n in nodes]
    for xw in (80.0, 100.0, 160.0):        # world-grid x (= HX + local); none over the gearboxes
        for s in (-1, 1):
            tops.append((xw - HX, s * (W / 2 - 4.0)))
    for y in (-60.0, -20.0, 20.0, 60.0):
        tops.append((L_S - 4.0, y))
    for (x, y) in tops:
        body = body.union(top_boss(x, y))

    # ---- cuts ----
    for (x, y) in tops:
        body = body.cut(top_ins(x, y))
    for s in (-1, 1):
        gx, gz, yf = motor_frame(s)
        ya, yb = sorted((s * (Y_IN - 1), s * (W / 2 + 1)))
        body = body.cut(cyl_y(ya, yb, AXLE_XL, AXLE_Z, BUSH_D))
        body = body.cut(cone((AXLE_XL, s * (Y_IN - 0.01), AXLE_Z), (0, s, 0), BUSH_D + 2.0, BUSH_D - 0.1, 1.05))
        for (hx_, hz_) in face_holes(s):
            body = body.cut(cyl_y(ya, yb, hx_, hz_, CLR_M3_H))
            # countersink from the outside face
            body = body.cut(cone((hx_, s * (W / 2 + 0.01), hz_), (0, -s, 0), CSK_M3_D + 0.02, CLR_M3_H,
                                 (CSK_M3_D - CLR_M3_H) / 2 + 0.01))
        # clamp bore + cap-screw inserts
        ya, yb = sorted((s * (Y_IN - SAD_U[1] - 1), s * (Y_IN - SAD_U[0] + 1)))
        body = body.cut(cyl_y(ya, yb, gx, gz, GB_BORE))
        yc = s * (Y_IN - SAD_U[1] - 0.01)
        body = body.cut(cone((gx, yc, gz), (0, s, 0), GB_BORE + 2.4, GB_BORE - 0.1, 1.25))
        for dx in (-1, 1):
            for u in (SAD_U[0] + 5.0, SAD_U[1] - 5.0):
                body = body.cut(cyl_z(gz - 8.0, gz + 1, gx + dx * CAP_BOLT_DX, s * (Y_IN - u), INS_M25))

    # joint: 45 deg notch for the centre lip, peg sockets, screw clearance, cable window
    c = SLIDE * math.sqrt(2)
    notch = [(-1.0, LIP_Z0 - c - 1.0), (LIP + SLIDE, LIP_Z0 - c + LIP + SLIDE), (LIP + SLIDE, H + 1), (-1.0, H + 1)]
    body = body.cut(prism_xz(notch, -W / 2 - 1, W / 2 + 1))
    for py in (-PEG_Y, PEG_Y):
        body = body.cut(prism_yz(diamond(py, PEG_Z, PEG_R + SLIDE * 1.42), -1, PEG_L + 0.6))
    for (y, z) in JOINT_SCREWS:
        body = body.cut(cyl_x(-1, BULK_T + 1, y, z, CLR_M25_H))
    body = body.cut(cable_window(-1, BULK_T + 1))
    # bumper: 2x2 M2.5 inserts for a front sensor bracket (D435 etc.)
    for y in (-25.0, 25.0):
        for z in (18.0, 38.0):
            body = body.cut(cyl_x(L_S - INS_DEPTH, L_S + 1, y, z, INS_M25))
    return body, tops

# =============================================================================
# SMALL PARTS
# =============================================================================
def motor_cap(s=1):
    gx, gz, _ = motor_frame(s)
    ya, yb = sorted((s * (Y_IN - SAD_U[1]), s * (Y_IN - SAD_U[0])))
    cap = box(gx - SAD_HW, gx + SAD_HW, ya, yb, gz + CLAMP_GAP, CAP_TOP)
    cap = cap.edges("|Y and >Z").fillet(8)
    cap = cap.cut(cyl_y(ya - 1, yb + 1, gx, gz, GB_BORE))
    for dx in (-1, 1):
        for u in (SAD_U[0] + 5.0, SAD_U[1] - 5.0):
            x, y = gx + dx * CAP_BOLT_DX, s * (Y_IN - u)
            cap = cap.cut(cyl_z(gz, CAP_TOP + 1, x, y, CLR_M25_V))
            cap = cap.cut(cyl_z(gz + CLAMP_GAP + 10.0, CAP_TOP + 1, x, y, 5.0))   # counterbore
    return cap

def wheel_adapter():
    """Local frame: axis +Z, z = distance from the gearbox face."""
    u_hub0, u_face = SIDE_T + 2.5, SIDE_T + WHEEL_GAP + WHEEL_WEB   # 8.0 .. 27.7
    fl_t, hub_d, fl_d = 6.0, 18.0, 31.0
    hub = cyl_z(u_hub0, u_face - fl_t + 0.01, 0, 0, hub_d)
    c45 = cone((0, 0, u_face - fl_t - (fl_d - hub_d) / 2), (0, 0, 1), hub_d, fl_d, (fl_d - hub_d) / 2 + 0.01)
    flange = cyl_z(u_face - fl_t, u_face, 0, 0, fl_d)
    a = hub.union(c45).union(flange)
    a = a.union(cyl_z(u_face - 0.01, u_face + 2.0, 0, 0, PILOT_D))
    # 8x M2.5 heat-set inserts: 4 on the wheel's 24 mm circle (4.0 holes) + 4 on its 16 mm circle (3.0 holes)
    for k in range(4):
        for r, t0 in ((12.0, 0.0), (8.0, 45.0)):
            t = math.radians(t0 + 90 * k)
            a = a.cut(cyl_z(u_face - 5.5, u_face + 3, r * math.cos(t), r * math.sin(t), INS_M25))
    # D bore
    bore = cyl_z(u_hub0 - 1, u_hub0 + 14.6, 0, 0, DBORE_D).intersect(
        box(-10, DFLAT, -10, 10, u_hub0 - 2, u_hub0 + 20))
    a = a.cut(bore)
    a = a.cut(cone((0, 0, u_hub0 - 0.01), (0, 0, 1), DBORE_D + 1.2, DBORE_D - 0.2, 0.7))   # lead-in chamfer
    # radial M2.5 set screw onto the flat (heat-set insert from outside)
    a = a.cut(cyl_x(DFLAT - 0.5, hub_d / 2 + 1, 0, u_hub0 + 6.0, INS_M25))
    return a

def place_adapter(a, s):
    """Put the adapter on the left (s=1) or right (s=-1) axle in end-section local coords."""
    r = a.rotate((0, 0, 0), (1, 0, 0), -90) if s > 0 else a.rotate((0, 0, 0), (1, 0, 0), 90)
    return r.translate((AXLE_XL, s * Y_IN, AXLE_Z))

# --- reference-only: real motor STEP + a simplified wheel ---------------------
MOTOR_STEP = os.environ.get("MOTOR_STEP", "37d-gearmotor-19-30-encoder.step")
_motor_cache = {}
def motor_real(s):
    if "m" not in _motor_cache:
        m = cq.importers.importStep(MOTOR_STEP).translate((-19.93, 0, -19.92))
        _motor_cache["m"] = m
    m = _motor_cache["m"]
    base = m.rotate((0, 0, 0), (1, 0, 0), -90 if s > 0 else 90)
    clock = 200.0 if s > 0 else 340.0
    r = base.rotate((0, 0, 0), (0, 1, 0), clock)
    # place so the shaft centre sits on the axle and the face on the wall
    sh = np.array([0.0, -7.0, 0.0])
    def Rx(a):
        c, s_ = math.cos(a), math.sin(a); return np.array([[1, 0, 0], [0, c, -s_], [0, s_, c]])
    def Ry(a):
        c, s_ = math.cos(a), math.sin(a); return np.array([[c, 0, s_], [0, 1, 0], [-s_, 0, c]])
    R = Ry(math.radians(clock)) @ Rx(math.radians(-90 if s > 0 else 90))
    p = R @ sh
    return r.translate((AXLE_XL - p[0], s * Y_IN - p[1], AXLE_Z - p[2]))

def wheel_dummy(s):
    y0 = s * (W / 2 + WHEEL_GAP)
    ya, yb = sorted((y0, y0 + s * WHEEL_W))
    ring = cyl_y(ya, yb, AXLE_XL, AXLE_Z, 2 * WHEEL_RMAX).cut(cyl_y(ya - 1, yb + 1, AXLE_XL, AXLE_Z, 50))
    wa, wb = sorted((y0 + s * WHEEL_WEB, y0 + s * (WHEEL_WEB + WEB_T)))
    web = cyl_y(wa, wb, AXLE_XL, AXLE_Z, 52).cut(cyl_y(wa - 1, wb + 1, AXLE_XL, AXLE_Z, 8.1))
    for k in range(4):
        t = math.radians(45 + 90 * k)
        web = web.cut(cyl_y(wa - 1, wb + 1, AXLE_XL + 8 * math.cos(t), AXLE_Z + 8 * math.sin(t), 3.0))
        t = math.radians(90 * k)
        web = web.cut(cyl_y(wa - 1, wb + 1, AXLE_XL + 12 * math.cos(t), AXLE_Z + 12 * math.sin(t), 4.0))
    return ring.union(web)

# =============================================================================
def place_front(wp):
    return wp.translate((HX, 0, 0))

def place_rear(wp):
    return wp.rotate((0, 0, 0), (0, 0, 1), 180).translate((-HX, 0, 0))

def to_print(wp, flip=False):
    if flip:
        wp = wp.rotate((0, 0, 0), (1, 0, 0), 180)
    bb = wp.val().BoundingBox()
    return wp.translate((-(bb.xmin + bb.xmax) / 2, -(bb.ymin + bb.ymax) / 2, -bb.zmin))

def build(with_refs=True):
    center, c_tops = center_section()
    end, e_tops = end_section()
    adapter = wheel_adapter()
    parts = {
        "center_section_x1": to_print(center),
        "end_section_x2": to_print(end),
        "motor_cap_x4": to_print(motor_cap(1), flip=True),
        "wheel_adapter_x4": to_print(adapter),
    }
    asm = cq.Assembly(name="10C4I_v2")
    grey, white = cq.Color(0.32, 0.33, 0.36), cq.Color(0.88, 0.88, 0.86)
    asm.add(center, name="center_section", color=grey)
    asm.add(place_front(end), name="front_section", color=white)
    asm.add(place_rear(end), name="rear_section", color=white)
    for tag, place in (("F", place_front), ("R", place_rear)):
        for s, side in ((1, "L"), (-1, "R")):
            asm.add(place(motor_cap(s)), name=f"cap_{tag}{side}", color=white)
            asm.add(place(place_adapter(adapter, s)), name=f"adapter_{tag}{side}", color=cq.Color(0.85, 0.45, 0.1))
            if with_refs:
                asm.add(place(motor_real(s)), name=f"REF_motor_{tag}{side}", color=cq.Color(0.7, 0.7, 0.72))
                asm.add(place(wheel_dummy(s)), name=f"REF_wheel_{tag}{side}", color=cq.Color(0.1, 0.1, 0.1))
    asm.add(box(-BATT[1] / 2, BATT[1] / 2, -BATT[0] / 2, BATT[0] / 2, FLOOR, FLOOR + BATT[2]),
            name="REF_battery_6S_5200", color=cq.Color(0.2, 0.3, 0.6))
    return asm, parts, dict(center=center, end=end, adapter=adapter, c_tops=c_tops, e_tops=e_tops)

if __name__ == "__main__":
    out = os.environ.get("OUT_DIR", "out")
    os.makedirs(out, exist_ok=True)
    refs = os.path.exists(MOTOR_STEP)   # Pololu STEP is optional: without it, no REF_ motors/wheels
    if not refs:
        print(f"note: {MOTOR_STEP} not found, exporting without reference motors/wheels")
    asm, parts, raw = build(with_refs=refs)
    asm.export(os.path.join(out, "10C4I_v2_assembly.step"))
    for name, wp in parts.items():
        cq.exporters.export(wp, os.path.join(out, f"{name}.step"))
        cq.exporters.export(wp, os.path.join(out, f"{name}.stl"), tolerance=0.02, angularTolerance=0.05)
        bb = wp.val().BoundingBox()
        fits = (bb.xlen <= BED[0] and bb.ylen <= BED[1]) or (bb.ylen <= BED[0] and bb.xlen <= BED[1])
        print(f"{name:20s} {bb.xlen:6.1f} x {bb.ylen:6.1f} x {bb.zlen:5.1f}  vol {wp.val().Volume()/1000:6.1f} cm3  "
              f"fits MK4S: {fits and bb.zlen <= BED[2]}")

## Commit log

2026-08-15 Testing the URDF
    [robot.urdf.xacro]
2026-08-15 Removed untracked files
    [robot.urdf.xacro]
2026-09-13 Edited hero.png
    [robot.urdf.xacro]
2026-09-26 Add 10C4I CAD: source, STEP/STL exports, and per-part docs
    - cad/10C4I/src: CadQuery source for chassis v2 and the tolerance coupon
    - cad/10C4I/step, stl: exports for center section, end section, motor cap,
    wheel adapter, coupon, and the v2 assembly (no motor/wheel ref bodies)
    - cad/10C4I/parts: one page per part, plus the planned bare-motor gearbox
    and the superseded v1 chassis
    - cad/10C4I/mount_points: CSV + map of all 56 M2.5 mount inserts
    Claude-Session: https://claude.ai/code/session_01KcqGZVtJ6HUufLkw6tJ5jB
    [10C4I_mount_points.csv, 10C4I_tolerance_coupon.step, 10C4I_tolerance_coupon.stl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]
